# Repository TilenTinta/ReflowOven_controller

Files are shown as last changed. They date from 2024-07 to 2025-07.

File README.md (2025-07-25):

# Reflow Oven Controller

An open-source controller for converting a kitchen toaster oven into a reflow oven.

## Overview

This project consists of a PCB and firmware to convert a classic toaster oven into a temperature-controlled oven for PCB reflow.

### Oven Modes
- **Reflow** - Follows a predefined temperature curve for optimal PCB reflow.
- **Dry** - Maintains a defined temperature for a set duration (useful for drying components, filaments, etc.).

The oven used in this build is a budget-friendly (**40€**) **9L toaster oven** with two quartz heating elements (**BROCK TO9001B**). Despite initial concerns about heating speed, the small chamber allows it to reach the required temperatures quickly. The oven has been additionally insulated for improved performance.

A **solid-state relay (SSR)** is used for controlling the heating elements, and a **12V 5A power supply** powers the entire electronics system.

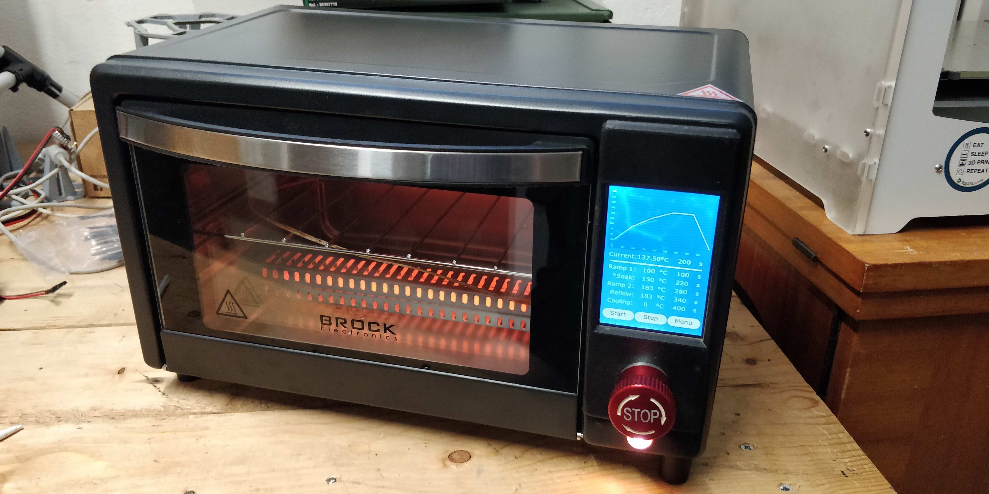
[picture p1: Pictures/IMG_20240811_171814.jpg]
Reflow Oven


---

## PCB

The PCB is a **two-layer board** with components on only one side (**except for the LCD connector, which is on the opposite side**). The board has the **same dimensions and mounting hole positions as the LCD**, allowing them to be stacked using a **3D-printed spacer**.

The LCD used in this build is a **3.5-inch TFT LCD Display Module (320x480) with SPI Interface and Touch Screen (ILI9488 v2).**

### PCB Features
- **Safety switch** for 12V
- **Voltage measurement** (input and buck output)
- **Overtemperature protection** via NTC sensor
- **Input protection** (fuse and reverse polarity protection)
- **Max input voltage: 23V**
- **AUX1 and AUX2** (can handle up to 45V and 500mA, but limited by PCB input voltage)
- **Supports up to two solid-state relays (SSRs)** (PWM amplitude matches input voltage)
- **Supports up to two K-type thermocouples (MAX31855)**
- **Raw USART output & USB output (CH340G)** for monitoring and calibration
- **USB OTG support** (requires core clock adjustment, affecting timer parameters)
- **External 2MB flash (W25Q16JVSNIQ)** for GUI and fonts
- **SWD port** for programming
- **Buzzer**
- **MCU: STM32F411CEU6**

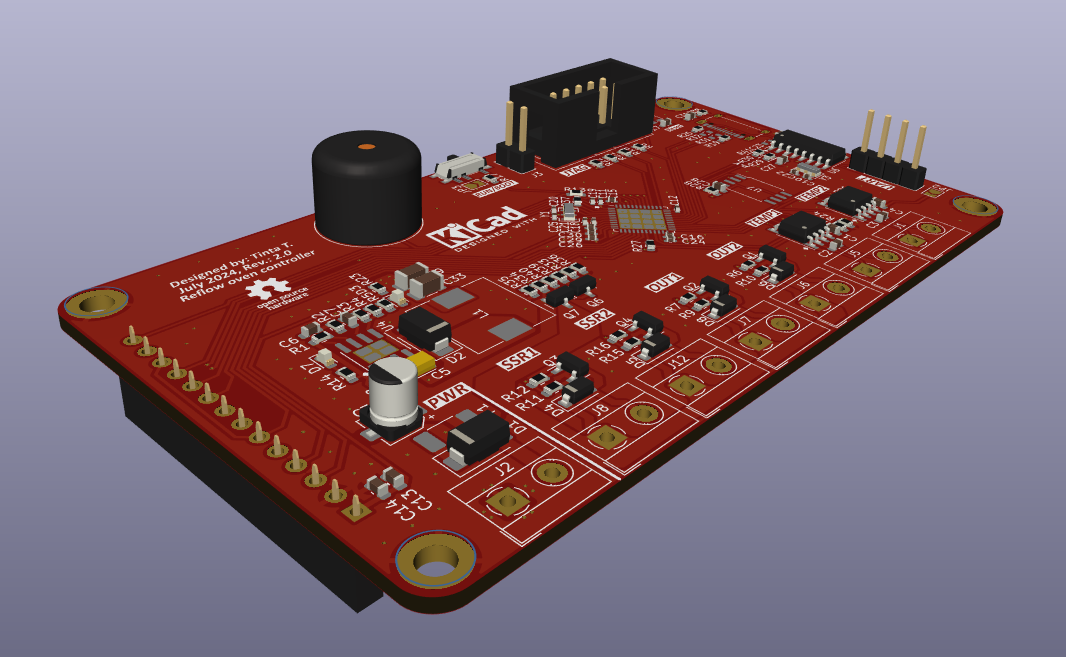
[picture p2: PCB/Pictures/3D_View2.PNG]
PCB 3D View


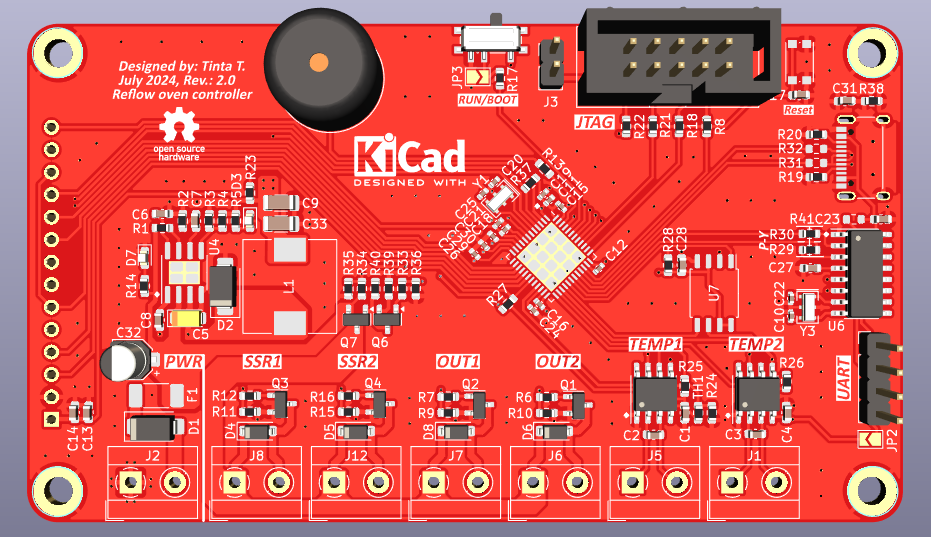
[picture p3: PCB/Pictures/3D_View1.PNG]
PCB 3D View


---

## 3D Models

All parts are printed from **PC plastic** using an **FDM 3D printer**. Alternative plastics can be used, but they must withstand high temperatures. There are two different options for electronics assembly mounting:
- Inside the oven as is in my case. For that you only need to print **Front_frame**

- On the side of the oven. For that you need to print three parts with **external** at the end of model names. Base that screws to the frame has teeth that allows preset angles. For rigit mount use only screw and nut, but you can add a spring under screw head. That will allow setting the angle later.

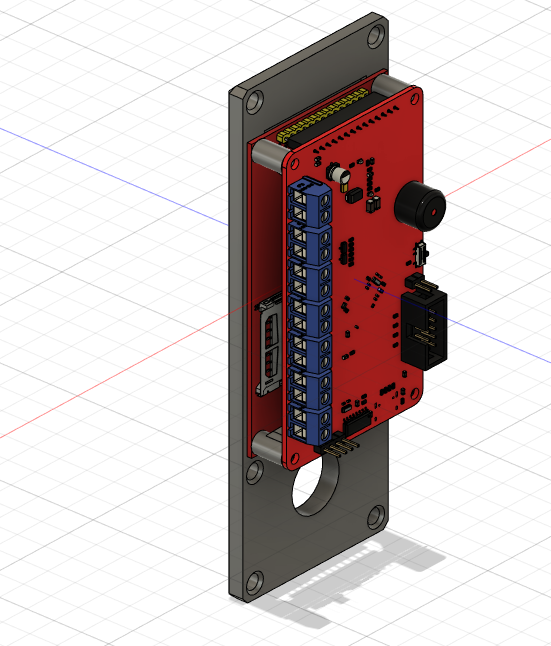
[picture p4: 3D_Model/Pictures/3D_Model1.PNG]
3D Model


---

## External Loader

The **External Loader** is a necessary part of the program. It allows **CubeIDE** to upload data (GUI and fonts) to the external flash chip. If you use a different flash chip, modifications are required to meet the new chip's recommendations. The loader program must be included in the main firmware/IDE.

---

## Firmware

The firmware is not fully compatible with the latest version of the PCB. This update addresses mistakes found in the initial version of the board.

### Missing Features
- **Read input voltage**
- **Read buck voltage**
- **Read NTC sensor**
- **Safety switch** (implemented in code but not tested)

For the GUI, **TouchGFX** with standard elements is used. The only custom file is the **background**.

### External Libraries Used
The libraries for **LCD (with touch)** and **external flash (External Loader)** are not originally written by me but include minor modifications to fit this build. The original work was done by **maudeve-it**:

#### LCD Library:
- [YouTube Video](https://www.youtube.com/watch?v=g1siKaPox88)
- [GitHub Repository](https://github.com/maudeve-it/ILI9XXX-XPT2046-STM32)

#### Flash Library:
- [YouTube Video 1](https://www.youtube.com/watch?v=PO_2ZE1NQF0&list=PL6Fwy7aR3zSlZO3OBppHSzDacE4CGgRqO&index=6)
- [YouTube Video 2](https://www.youtube.com/watch?v=KlG2doCkREM)
- [GitHub Repository](https://github.com/maudeve-it/W25Qxxx_SPI_FLASH_STM32)

---

## License
This project is open-source and available under the **MIT License**.

---

## Contributing
Contributions are welcome! Feel free to submit issues or pull requests to improve the project.

---

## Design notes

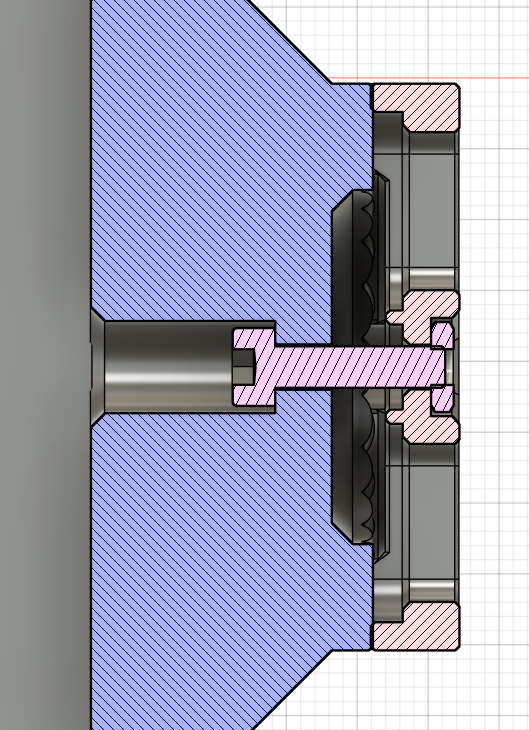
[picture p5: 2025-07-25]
3D_Model/Pictures/External_mount.PNG

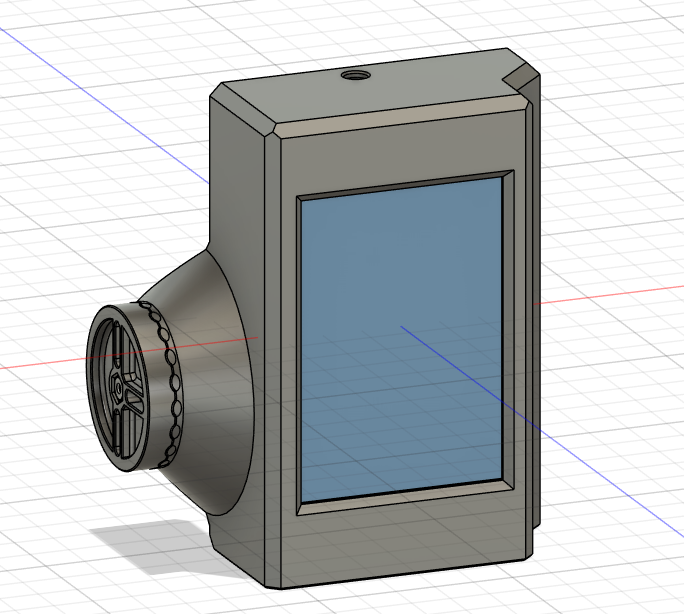
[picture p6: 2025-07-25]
3D_Model/Pictures/External_mount_case.PNG

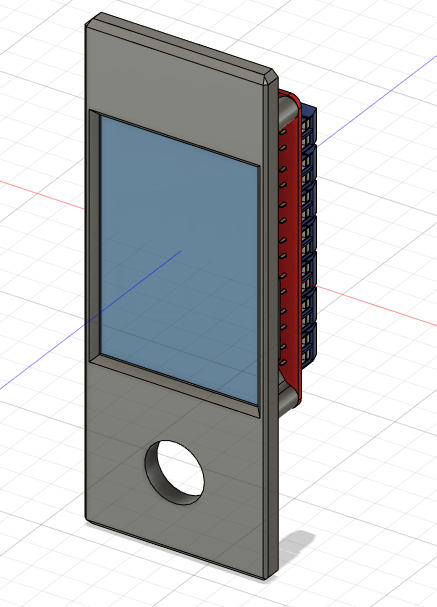
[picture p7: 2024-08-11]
3D_Model/Pictures/3D_Model2.PNG

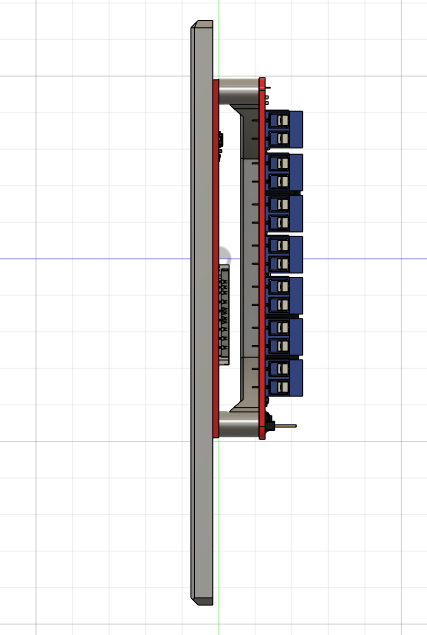
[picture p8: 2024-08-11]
3D_Model/Pictures/3D_Model3.PNG

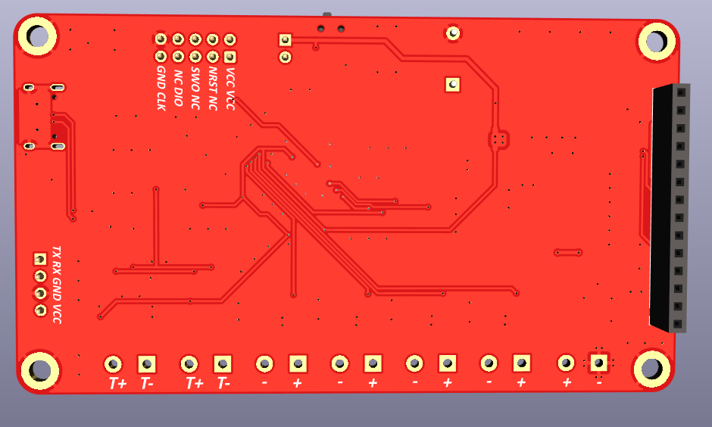
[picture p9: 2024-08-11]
PCB/Pictures/3D_View4.PNG

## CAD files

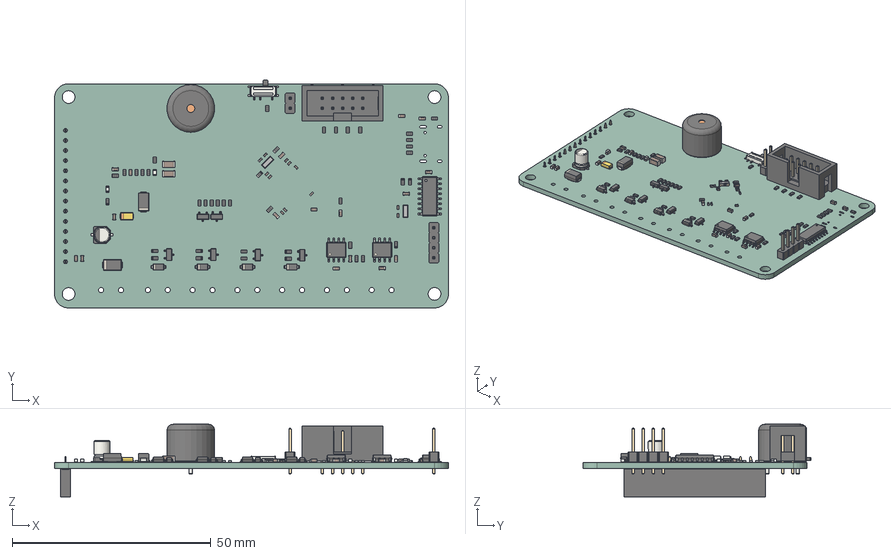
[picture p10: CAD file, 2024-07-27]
3D_Model/PCB.step
99.0 x 57.3 x 18.2 mm
R_0603_1608Metric x 41
Buzzer_12x95RM76
PinHeader_1x04_P254mm_Vertical
C_0402_1005Metric x 12
C_1206_3216Metric x 2
LED_0603_1608Metric x 2
CP_Elec_4x54
muRata_CSTxExxV x 2
SOT_23 x 6
D_SMA x 2
PinHeader_1x02_P254mm_Vertical
C_0603_1608Metric x 17
Fusion_sp
IDC_Header_2x05_P254mm_Vertical
CP_EIA_3216_10_Kemet_I
SOIC_8_39x49mm_P127mm x 2
D_SOD_123 x 4
SOIC_16_39x99mm_P127mm
PinSocket_1x14_P254mm_Vertical
PCB_PCB

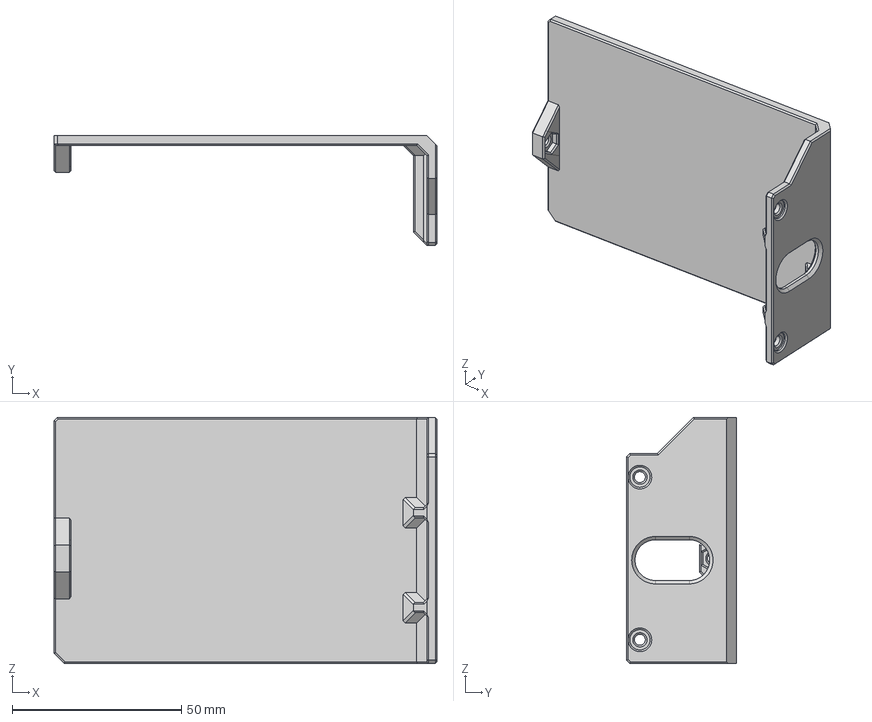
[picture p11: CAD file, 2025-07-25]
3D_Model/STEP/Back_frame_external v19.step
113.0 x 32.5 x 72.6 mm

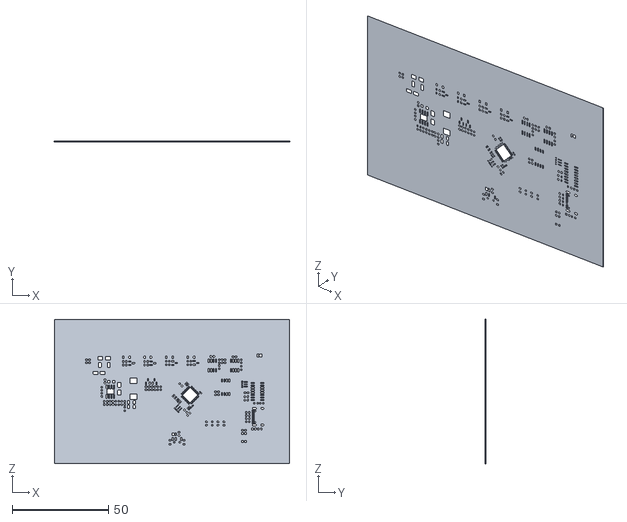
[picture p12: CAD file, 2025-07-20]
PCB/Stencil/Stencil v2.stl
122.1 x 0.15 x 75.0

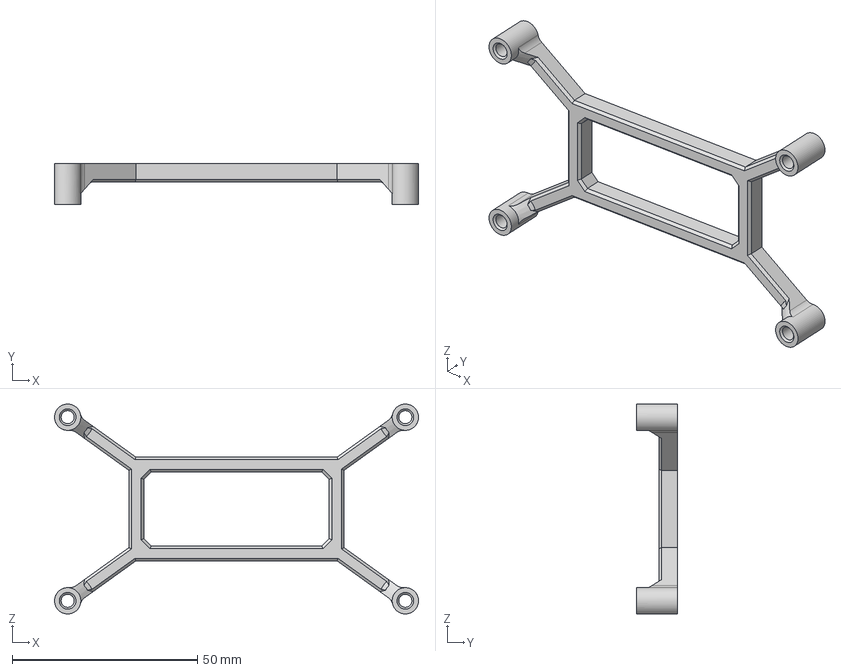
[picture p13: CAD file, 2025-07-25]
3D_Model/STEP/Spacer_PCB-Screen v3.step
98.1 x 11.0 x 56.6 mm

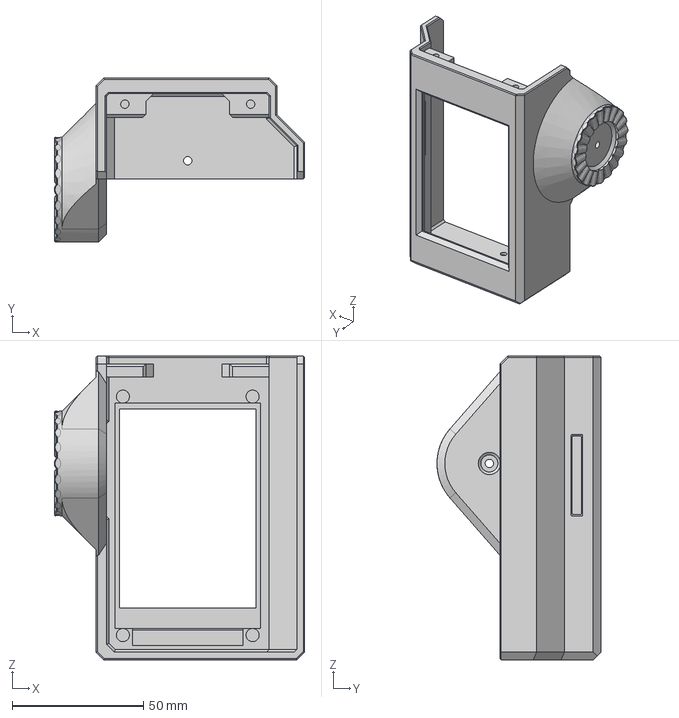
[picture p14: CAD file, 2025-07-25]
3D_Model/STEP/Front_frame_external v40.step
95.5 x 62.6 x 116.0 mm

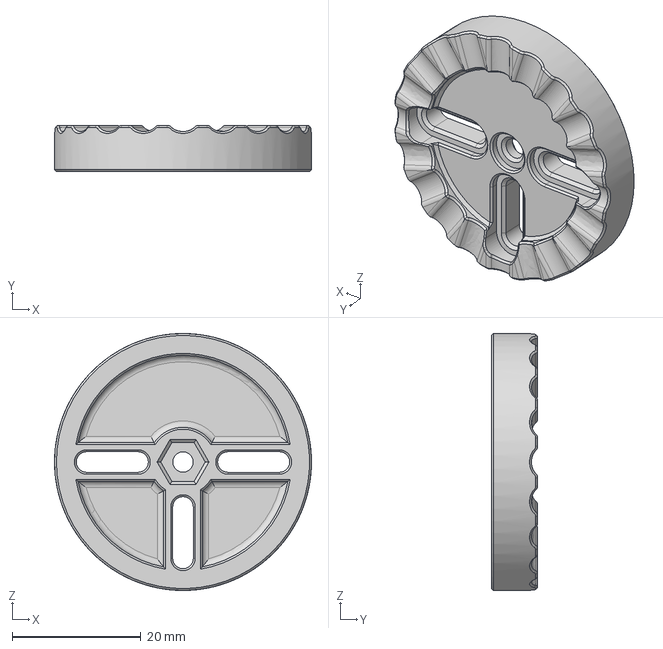
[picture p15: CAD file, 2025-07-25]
3D_Model/STEP/Base_external v7.step
40.0 x 7.20 x 40.0 mm

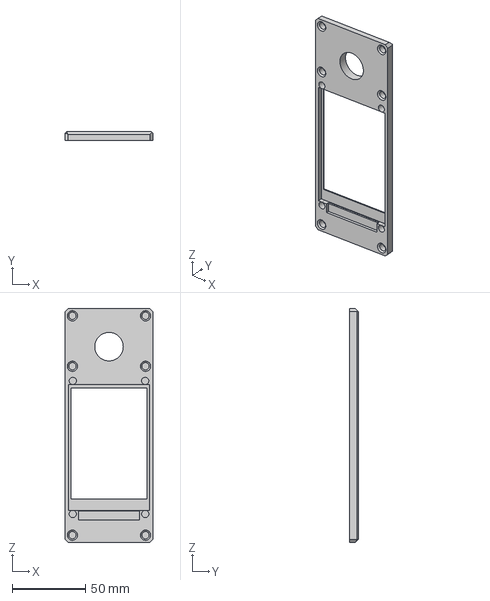
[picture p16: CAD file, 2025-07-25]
3D_Model/STEP/Front_frame v9.step
60.0 x 6.00 x 160.0 mm

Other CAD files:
3D_Model/STL/Back_frame_external v19.stl
3D_Model/STL/Base_external v7.stl
3D_Model/STL/Front_frame v9.stl
3D_Model/STL/Front_frame_external v40.stl
3D_Model/STL/Spacer_PCB-Screen v3.stl
PCB/Stencil/PCB-F_Mask.dxf

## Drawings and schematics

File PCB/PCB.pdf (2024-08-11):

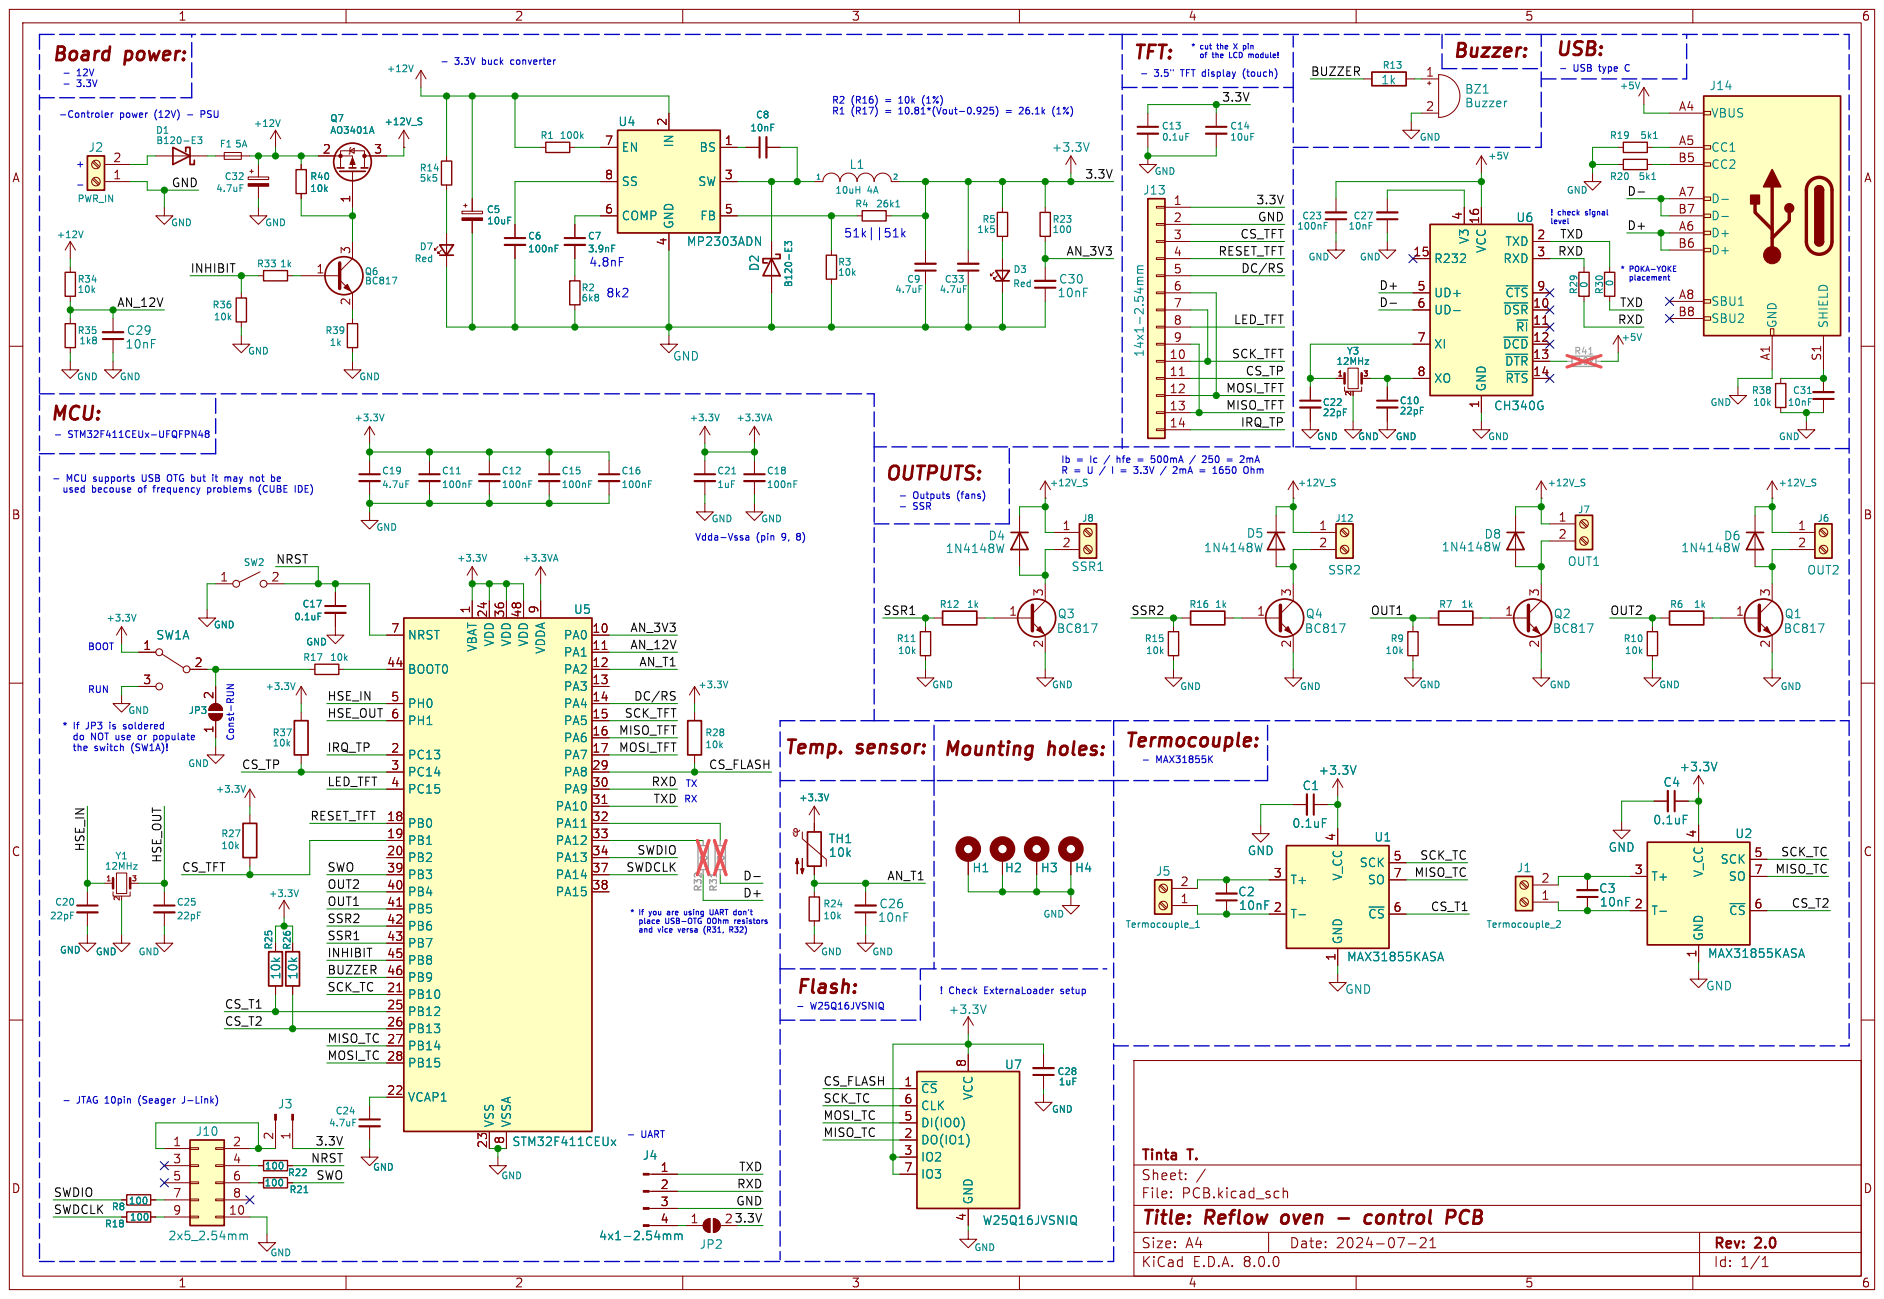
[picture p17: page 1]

4 FB 5 COMP 6 EN 7 SS 8 U4 MP2303ADN

4 FB 5 COMP 6 EN 7 SS 8 D2 B120-E3 C5

1 ~{DSR} 10 ~{RI} 11 ~{DCD} 12 ~{DTR} 13 ~{RTS} 14 R232 15 VCC 16 TXD 2 RXD 3 V3

4 UD+ 5 UD- 6 XI 7 XO 8 ~{CTS}9 U6 CH340G

4 UD+ 5 UD- 6 XI 7 XO 8 ~{CTS}9 C3

Ib = Ic / hfe = 500mA / 250 = 2mA R = U / I = 3.3V / 2mA = 1650 Ohm

- JTAG 10pin (Seager J-Link) Const-RUN

1 PA0 10 PA1 11 PA2 12 PA3 13 PA4 14 PA5 15 PA6 16 PA7 17 PB0 18 PB1 19 PC13 2 PB2 20 PB10 21 VCAP1 22 VSS 23 VDD 24 PB12 25 PB13 26 PB14 27 PB15 28 PA8 29 PC14 3 PA9 30 PA10 31 PA11 32 PA12 33 PA13 34 VDD 36 PA14 37 PA15 38 PB3 39 PC15 4 PB4 40 PB5 41 PB6 42 PB7 43 BOOT0 44 PB8 45 PB9 46 VDD 48 PH0 5 PH1 6 NRST 7 VSSA

4 SCK 5 ~{CS}6 SO 7 U5 STM32F411CEUx VBAT

* If JP3 is soldered
do NOT use or populate

4 SCK 5 ~{CS}6 SO 7 U1 MAX31855KASA GND

* If you are using UART don't place USB-OTG 0Ohm resistors and vice versa (R31, R32)

Id: 1/1 Title: Reflow oven - control PCB

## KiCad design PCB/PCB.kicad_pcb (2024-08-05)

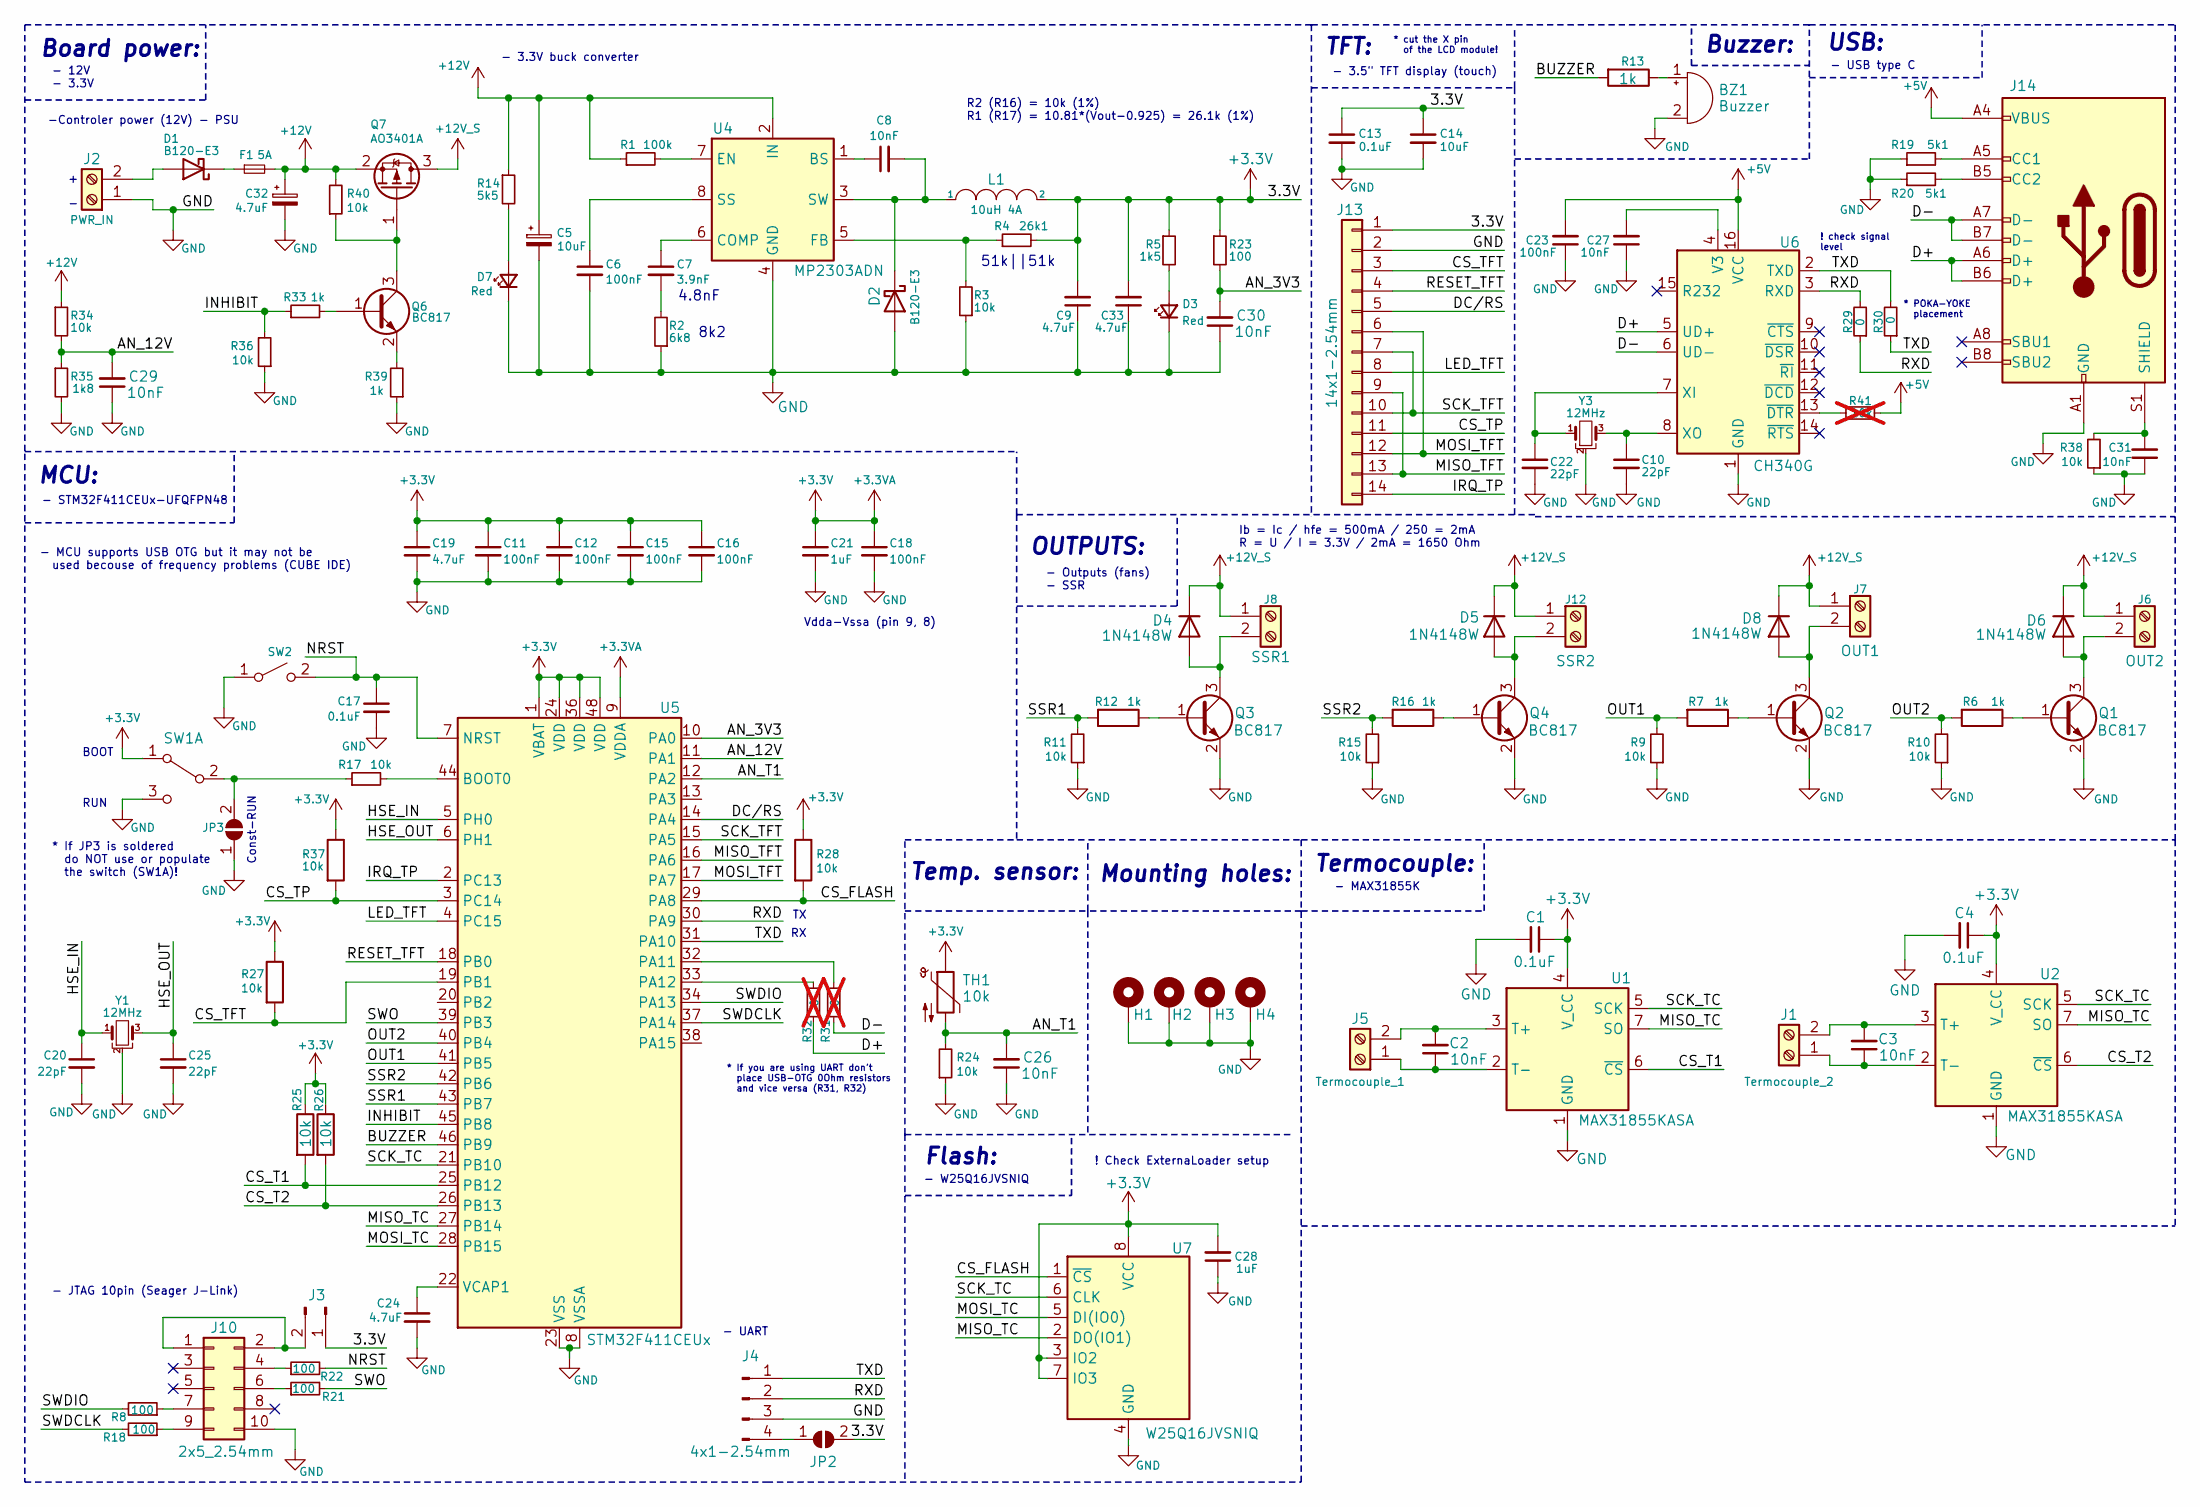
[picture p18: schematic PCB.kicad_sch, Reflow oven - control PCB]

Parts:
BZ1: Buzzer; Buzzer_12x9.5RM7.6
C1, C4, C13, C17: 0.1uF; C_0603_1608Metric
C2, C3, C8, C27, C31: 10nF; C_0603_1608Metric
C5: 10uF; CP_EIA-3216-10_Kemet-I
C6, C23: 100nF; C_0603_1608Metric
C7: 3.9nF; C_0603_1608Metric
C9, C33: 4.7uF; C_1206_3216Metric
C10, C20, C22, C25: 22pF; C_0402_1005Metric
C11, C12, C15, C16, C18: 100nF; C_0402_1005Metric
C14: 10uF; C_0603_1608Metric
C19, C24: 4.7uF; C_0402_1005Metric
C21: 1uF; C_0402_1005Metric
C26, C29, C30: 10nF; C_0402_1005Metric
C28: 1uF; C_0603_1608Metric
C32: 4.7uF; CP_Elec_4x5.4
D1, D2: B120-E3; D_SMA
D3, D7: Red; LED_0603_1608Metric
D4, D5, D6, D8: 1N4148W; D_SOD-123
F1: 5A; Fuse_2010_5025Metric_Pad1.52x2.65mm_HandSolder
H1, H2, H3, H4: MountingHole_Pad; MountingHole_3.2mm_M3_DIN965_Pad
J1: Termocouple_2; TerminalBlock_MetzConnect_Type055_RT01502HDWU_1x02_P5.00mm_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
J2: PWR_IN; TerminalBlock_MetzConnect_Type055_RT01502HDWU_1x02_P5.00mm_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
J3: Conn_01x02_Pin; PinHeader_1x02_P2.54mm_Vertical
J4: 4x1-2.54mm; PinHeader_1x04_P2.54mm_Vertical
J5: Termocouple_1; TerminalBlock_MetzConnect_Type055_RT01502HDWU_1x02_P5.00mm_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
J6: OUT2; TerminalBlock_MetzConnect_Type055_RT01502HDWU_1x02_P5.00mm_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
J7: OUT1; TerminalBlock_MetzConnect_Type055_RT01502HDWU_1x02_P5.00mm_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
J8: SSR1; TerminalBlock_MetzConnect_Type055_RT01502HDWU_1x02_P5.00mm_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
J10: 2x5_2.54mm; IDC-Header_2x05_P2.54mm_Vertical
J12: SSR2; TerminalBlock_MetzConnect_Type055_RT01502HDWU_1x02_P5.00mm_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
J13: 14x1-2.54mm; PinSocket_1x14_P2.54mm_Vertical
J14: USB_C_Receptacle_USB2.0; USB_C_Receptacle_XKB_U262-16XN-4BVC11
JP2, JP3: SolderJumper_2_Open; SolderJumper-2_P1.3mm_Open_TrianglePad1.0x1.5mm
L1: 10uH 4A; L_10.4x10.4_H4.8
Q1, Q2, Q3, Q4, Q6: BC817; SOT-23
Q7: AO3401A; SOT-23
R1: 100k; R_0603_1608Metric
R2: 6k8; R_0603_1608Metric
R3, R9, R10, R11, R15, R17, R24, R25, R26, R27, R28, R34, R36, R37, R38, R40: 10k; R_0603_1608Metric
R4: 26k1; R_0603_1608Metric
R5: 1k5; R_0603_1608Metric
R6, R7, R12, R13, R16, R33, R39: 1k; R_0603_1608Metric
R8, R18, R21, R22, R23: 100; R_0603_1608Metric
R14: 5k5; R_0603_1608Metric
R19, R20: 5k1; R_0603_1608Metric
R29, R30: 0; R_0603_1608Metric
R31, R32: 0; R_0603_1608Metric; not fitted
R35: 1k8; R_0603_1608Metric
R41: 10k; R_0603_1608Metric; not fitted
SW1: SW_DPDT; SW_SPDT_PCM12
SW2: SW_SPST; SW_Push_1P1T_NO_CK_KMR2
TH1: 10k; R_0603_1608Metric
U1, U2: MAX31855KASA; SOIC-8_3.9x4.9mm_P1.27mm
U4: MP2303ADN; SOIC-8-1EP_3.9x4.9mm_P1.27mm_EP2.62x3.51mm
U5: STM32F411CEUx; QFN-48-1EP_7x7mm_P0.5mm_EP5.6x5.6mm
U6: CH340G; SOIC-16_3.9x9.9mm_P1.27mm
U7: W25Q16JVSNIQ; SOIC-8_5.23x5.23mm_P1.27mm
Y1, Y3: 12MHz; Resonator_SMD_Murata_CSTxExxV-3Pin_3.0x1.1mm

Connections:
+3.3V: C1.1, C4.1, C9.2, C11.1, C12.1, C13.1, C14.1, C15.1, C16.1, C18.1, C19.1, C21.1, C28.2, C33.2, J3.1, J13.1, JP2.2 (B), L1.2, R4.2, R5.1, R23.1, R25.1, R26.1, R27.1, R28.1, R37.1, SW1.1 (A), TH1.1, U1.4 (V_CC), U2.4 (V_CC), U5.1 (VBAT), U5.9 (VDDA), U5.24 (VDD), U5.36 (VDD), U5.48 (VDD), U7.3 (IO2), U7.7 (IO3), U7.8 (VCC)
+5V: C23.2, J14.A4 (VBUS), J14.A9 (VBUS), J14.B4 (VBUS), J14.B9 (VBUS), R41.1, U6.16 (VCC)
+12V: C5.1, C32.1, F1.2, Q7.2 (S), R1.1, R14.1, R34.1, R40.2, U4.2 (IN)
+12V_S: D4.1 (K), D5.1 (K), D6.1 (K), D8.1 (K), J6.1, J7.1, J8.1, J12.1, Q7.3 (D)
/AN_3V3: C30.2, R23.2, U5.10 (PA0)
/AN_12V: C29.2, R34.2, R35.1, U5.11 (PA1)
/AN_T1: C26.2, R24.2, TH1.2, U5.12 (PA2)
/BUZZER: R13.2, U5.46 (PB9)
/CS_FLASH: R28.2, U5.29 (PA8), U7.1 (~CS)
/CS_T1: R25.2, U1.6 (~CS), U5.25 (PB12)
/CS_T2: R26.2, U2.6 (~CS), U5.26 (PB13)
/CS_TFT: J13.3, R27.2, U5.19 (PB1)
/CS_TP: J13.11, R37.2, U5.3 (PC14)
/D+: J14.A6 (D+), J14.B6 (D+), R32.1, U6.5 (UD+)
/D-: J14.A7 (D-), J14.B7 (D-), R31.1, U6.6 (UD-)
/DC/RS: J13.5, U5.14 (PA4)
/HSE_IN: C20.1, U5.5 (PH0), Y1.1
/HSE_OUT: C25.1, U5.6 (PH1), Y1.3
/INHIBIT: R33.1, R36.2, U5.45 (PB8)
/IRQ_TP: J13.14, U5.2 (PC13)
/LED_TFT: J13.8, U5.4 (PC15)
/MISO_TC: U1.7 (SO), U2.7 (SO), U5.27 (PB14), U7.2 (DO(IO1))
/MISO_TFT: J13.9, J13.13, U5.16 (PA6)
/MOSI_TC: U5.28 (PB15), U7.5 (DI(IO0))
/MOSI_TFT: J13.6, J13.12, U5.17 (PA7)
/NRST: C17.1, R22.2, SW2.2 (B), U5.7 (NRST)
/OUT1: R7.2, R9.2, U5.41 (PB5)
/OUT2: R6.2, R10.2, U5.40 (PB4)
/RESET_TFT: J13.4, U5.18 (PB0)
/RXD: J4.2, R29.1, R29.2, U5.30 (PA9), U6.3 (RXD)
/SCK_TC: U1.5 (SCK), U2.5 (SCK), U5.21 (PB10), U7.6 (CLK)
/SCK_TFT: J13.7, J13.10, U5.15 (PA5)
/SSR1: R11.2, R12.2, U5.43 (PB7)
/SSR2: R15.2, R16.2, U5.42 (PB6)
/SWDCLK: R18.2, U5.37 (PA14)
/SWDIO: R8.2, U5.34 (PA13)
/SWO: R21.2, U5.39 (PB3)
/TXD: J4.1, R30.1, R30.2, U5.31 (PA10), U6.2 (TXD)
GND: BZ1.2 (+), C1.2, C4.2, C5.2, C6.2, C9.1, C10.2, C11.2, C12.2, C13.2, C14.2, C15.2, C16.2, C17.2, C18.2, C19.2, C20.2, C21.2, C22.2, C23.1, C24.2, C25.2, C26.1, C27.1, C28.1, C29.1, C30.1, C31.1, C32.2, C33.1, D2.2 (A), D3.1 (K), D7.1 (K), H1.1, H2.1, H3.1, H4.1, J2.1, J4.3, J10.10, J13.2, J14.A1 (GND), J14.A12 (GND), J14.B1 (GND), J14.B12 (GND), JP3.1 (A), Q1.2 (E), Q2.2 (E), Q3.2 (E), Q4.2 (E), R2.1, R3.1, R9.1, R10.1, R11.1, R15.1, R19.1, R20.1, R24.1, R35.2, R36.1, R38.1, R39.1, SW1.3 (C), SW2.1 (A), U1.1 (GND), U2.1 (GND), U4.4 (GND), U5.8 (VSSA), U5.23 (VSS), U5.35 (VSS), U5.47 (VSS), U5.49 (VSS), U6.1 (GND), U7.4 (GND), Y1.2, Y3.2
unnamed: BZ1.1 (-), R13.1
unnamed: C7.2, R2.2
unnamed: D1.2 (A), J2.2
unnamed: D1.1 (K), F1.1
unnamed: C8.2, D2.1 (K), L1.1, U4.3 (SW)
unnamed: D3.2 (A), R5.2
unnamed: D4.2 (A), J8.2, Q3.3 (C)
unnamed: D5.2 (A), J12.2, Q4.3 (C)
unnamed: D6.2 (A), J6.2, Q1.3 (C)
unnamed: D7.2 (A), R14.2
unnamed: D8.2 (A), J7.2, Q2.3 (C)
unnamed: C3.1, J1.1, U2.2 (T-)
unnamed: C3.2, J1.2, U2.3 (T+)
unnamed: J4.4, JP2.1 (A)
unnamed: C2.1, J5.1, U1.2 (T-)
unnamed: C2.2, J5.2, U1.3 (T+)
unnamed: J3.2, J10.1, J10.2
unnamed: J10.4, R22.1
unnamed: J10.6, R21.1
unnamed: J10.7, R8.1
unnamed: J10.9, R18.1
unnamed: J14.A5 (CC1), R19.2
unnamed: J14.B5 (CC2), R20.2
unnamed: C31.2, J14.S1 (SHIELD), R38.2
unnamed: JP3.2 (B), R17.1, SW1.2 (B)
unnamed: Q1.1 (B), R6.1
unnamed: Q2.1 (B), R7.1
unnamed: Q3.1 (B), R12.1
unnamed: Q4.1 (B), R16.1
unnamed: Q6.1 (B), R33.2
unnamed: Q6.3 (C), Q7.1 (G), R40.1
unnamed: Q6.2 (E), R39.2
unnamed: C8.1, U4.1 (BS)
unnamed: C7.1, U4.6 (COMP)
unnamed: R1.2, U4.7 (EN)
unnamed: R3.2, R4.1, U4.5 (FB)
unnamed: C6.1, U4.8 (SS)
unnamed: R17.2, U5.44 (BOOT0)
unnamed: R31.2, U5.32 (PA11)
unnamed: R32.2, U5.33 (PA12)
unnamed: C24.1, U5.22 (VCAP1)
unnamed: C27.2, U6.4 (V3)
unnamed: C22.1, U6.7 (XI), Y3.1
unnamed: C10.1, U6.8 (XO), Y3.3
unnamed: R41.2, U6.13 (~DTR)

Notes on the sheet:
Ib = Ic / hfe = 500mA / 250 = 2mA R = U / I = 3.3V / 2mA = 1650 Ohm
R2 (R16) = 10k (1%) R1 (R17) = 10.81*(Vout-0.925) = 26.1k (1%)
8k2
BOOT
Temp. sensor:
* POKA-YOKE placement
! check signal level
MCU:
Vdda-Vssa (pin 9, 8)
Buzzer:
* cut the X pin of the LCD module!
* If JP3 is soldered do NOT use or populate the switch (SW1A)!
4.8nF
- MAX31855K
Termocouple:
- UART
OUTPUTS:
Board power:
- JTAG 10pin (Seager J-Link)
- MCU supports USB OTG but it may not be used becouse of frequency problems (CUBE IDE)
TFT:
- Outputs (fans) - SSR
! Check ExternaLoader setup
- 12V - 3.3V
- 3.3V buck converter
- 3.5" TFT display (touch)
USB:
Mounting holes:
- USB type C
Flash:
-Controler power (12V) - PSU
Const-RUN
51k||51k
* If you are using UART don't place USB-OTG 0Ohm resistors and vice versa (R31, R32)
- W25Q16JVSNIQ
RUN
- STM32F411CEUx-UFQFPN48

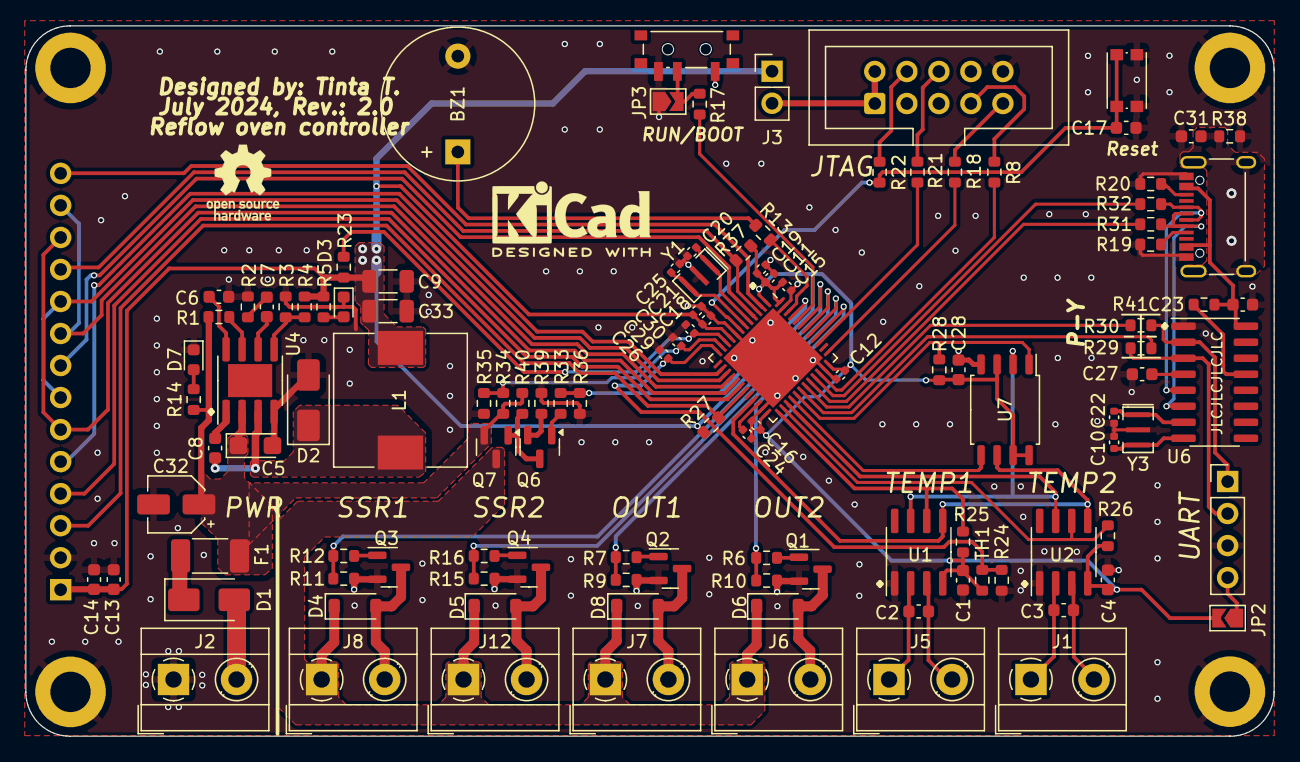
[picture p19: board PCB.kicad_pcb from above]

Board: 2 copper layers, 99.0 x 56.3 mm, 120 parts (1 on the bottom side), 84 nets.

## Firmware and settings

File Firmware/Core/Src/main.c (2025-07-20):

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
/* Includes ------------------------------------------------------------------*/
#include "main.h"
#include "app_touchgfx.h"

CRC_HandleTypeDef hcrc;

SPI_HandleTypeDef hspi1;
SPI_HandleTypeDef hspi2;
DMA_HandleTypeDef hdma_spi1_tx;

TIM_HandleTypeDef htim2;
TIM_HandleTypeDef htim3;
TIM_HandleTypeDef htim4;

UART_HandleTypeDef huart1;

void SystemClock_Config(void);
static void MX_GPIO_Init(void);
static void MX_DMA_Init(void);
static void MX_USART1_UART_Init(void);
static void MX_SPI1_Init(void);
static void MX_CRC_Init(void);
static void MX_SPI2_Init(void);
static void MX_TIM3_Init(void);
static void MX_TIM2_Init(void);
static void MX_TIM4_Init(void);
/* USER CODE BEGIN PFP */
// Define structs
Thermocouple thermocouple1;
Thermocouple thermocouple2;

/* USER CODE END PFP */

/* USER CODE BEGIN 0 */

// Default values for oven preset
OvenParameters ovenParameters = {

		// device operating variables
		.initEnd = 0,
		.deviceState = 0,
		.pageChageNo = 0,
		.reflowSetupStep = 0,
		.pidSetupStep = 0,
		.tempNTC = 0.0f,
		.tempThermo = 0.0f,
		.PID_trig = 0,
		.saveFlash = 0,
		.reflowStage = 0,
		.tempSPDelta = 0,
		.setpointCal = 1,
		.totalReflowTime = 0,
		.endTimeStage = 1,
		.tempThermoAvg = 0,
		.addPoint = 0,
		.profileNoEdit = 0,

		// retentive variables
		.Kp = 10.0f,	// 3.96
		.Ki = 0.1f,		// 0.078
		.Kd = 4.5f,		// 49.5
		.profileNoSelected = 2,
		.lastUsedMode = 0,

		.dualProbes = 0,
		.dualSSRs = 0,
		.units = 0,
		.AUX1 = 0,
		.AUX2 = 0,
		.firstBoot = 0,

		// device runing variables
		.startStop = 0,
		.actionTick = 0,
		.cntTimerTick = 0,
		.cntSecond = 0,
		.cntMinute = 0,
		.cntHour = 0
};

// Default values for profiles
ReflowProfiles reflowProfiles = {
		.profile1Temp = {150, 160, 210, 210, 20},
		.profile1Time = {120, 140, 390, 400, 450},

		.profile2Temp = {100, 150, 183, 183, 20},
		.profile2Time = {100, 220, 280, 340, 400},

		.profile3Temp = {100, 150, 183, 183, 20},
		.profile3Time = {100, 220, 280, 340, 400},

		.profile4Temp = {100, 150, 183, 183, 20},
		.profile4Time = {100, 220, 280, 340, 400},

		.profile5Temp = {100, 150, 183, 183, 20},
		.profile5Time = {100, 220, 280, 340, 400}
};

// Default values for drying
DryPreset dryPreset = {
		.dryTemp = 100,
		.dryTime = 60
};

// Default values for error codes
OvenErrorCodes ovenErrorCodes = {
		.ADC12V = 0,
		.ADC3V3 = 0,
		.NTCErr = 0,
		.thermoCouple1Err = 0,
		.thermoCouple2Err = 0
};


// variables init
float AN_V_12V = 0;				// Measured 12V voltage
float AN_V_3V3 = 0;				// Measured 3.3V voltage
uint8_t INHIBIT = 0;			// enable 12V bus

uint8_t saveToFlash = 0;		// protect writing to flash every time (connected with KEEP_FLASH_DATA)
float tempAVG1[5] = {};			// values of temp from thermocouple 1 in one second to calculate average value
float tempAVG2[5] = {};			// values of temp from thermocouple 2 in one second to calculate average value
uint8_t cntTempArray = 0;		// counter for temperature array
uint8_t endOfCycle = 0;			// flag to indicate the end of drying or reflow
float startingTemp = 0; 		// used to set setpoints
uint16_t endTemp = 0;			// temperature expected at the end of each step
uint8_t thermalRnwyCnt = 0;		// counter for thermal runaway time - one tick is one second
uint16_t rnwyTempOld = 0;		// previous temp value for detecting thermal runaways

/* USER CODE END 0 */

/**
  * @brief  The application entry point.
  * @retval int
  */
int main(void)
{

  /* USER CODE BEGIN 1 */

	// TODO: Celsius -> Fahrenheit

	// PID parameters
	PID pid;
	PIDInit(&pid);

  /* USER CODE END 1 */

  /* MCU Configuration--------------------------------------------------------*/

  /* Reset of all peripherals, Initializes the Flash interface and the Systick. */
  HAL_Init();

  /* Configure the system clock */
  SystemClock_Config();

  /* Initialize all configured peripherals */
  MX_GPIO_Init();
  MX_DMA_Init();
  MX_USART1_UART_Init();
  MX_SPI1_Init();
  MX_CRC_Init();
  MX_SPI2_Init();
  MX_TIM3_Init();
  MX_TIM2_Init();
  MX_TIM4_Init();
  MX_TouchGFX_Init();
  /* USER CODE BEGIN 2 */

  // Set default state of CS and other pins
  HAL_GPIO_WritePin(TOUCH_CS_GPIO_Port, TOUCH_CS_Pin, GPIO_PIN_SET);
  HAL_GPIO_WritePin(DISPL_CS_GPIO_Port, DISPL_CS_Pin, GPIO_PIN_SET);
  HAL_GPIO_WritePin(FLASH_CS_GPIO_Port, FLASH_CS_Pin, GPIO_PIN_SET);
  HAL_GPIO_WritePin(TERMO1_CS_GPIO_Port, TERMO1_CS_Pin, GPIO_PIN_SET);
  HAL_GPIO_WritePin(TERMO2_CS_GPIO_Port, TERMO2_CS_Pin, GPIO_PIN_SET);
  HAL_GPIO_WritePin(AUX_OUT1_GPIO_Port, AUX_OUT1_Pin, GPIO_PIN_RESET);
  HAL_GPIO_WritePin(AUX_OUT2_GPIO_Port, AUX_OUT2_Pin, GPIO_PIN_RESET);
  HAL_GPIO_WritePin(DISPL_LED_GPIO_Port, DISPL_LED_Pin, GPIO_PIN_SET);

  Displ_Init(Displ_Orientat_90);			// initialize display controller - set orientation parameter as per TouchGFX setup
  Displ_BackLight('I');  					// initialize backlight
  touchgfxSignalVSync();
  HAL_TIM_Base_Start_IT(&TGFX_T);			// start TouchGFX tick timer

  /* USER CODE END 2 */

  /* Infinite loop */
  /* USER CODE BEGIN WHILE */


  while (1)
  {

	  if (Touch_GotATouch(0))
		  touchgfxSignalVSync();
    /* USER CODE END WHILE */

  MX_TouchGFX_Process();
    /* USER CODE BEGIN 3 */

	  // Timer interrupt trigger (5Hz)
	  if (ovenParameters.actionTick == 1)
	  {
		  // To start timer the device must be in run mode (startStop = 1)
		  if (ovenParameters.startStop == 1)
		  {
			  // Ticks to seconds
			  // that part of code is implemented in interrupt routine becouse of precision

			  // Seconds to minutes
			  if (ovenParameters.cntSecond >= secInMin)
			  {
				  ovenParameters.cntSecond = 0;
				  ovenParameters.cntMinute ++;


				// THERMAL RUNAWAY LOGIC //
				/* if the device has enabled one or both SSRs and
				 * the temperature doesn't reach setted delta temerature
				 * the error is triggered
				*/
				#ifdef THERMAL_RUNAWAY_EN
				  rnwyTempOld = ovenParameters.tempThermoAvg;

				  if (ovenParameters.dualSSRs == 0)				 // The value can be adjusted
				  {
					  if (TIM4->CCR2 > 5000)
					  {
						  thermalRnwyCnt = ((rnwyTempOld - ovenParameters.tempThermoAvg) < RUNAWAY_TEMP) ? (thermalRnwyCnt + 1) : 0;
					  }
				  }
				  else
				  {
					  if (TIM4->CCR2 > 5000 || TIM4->CCR1 > 5000) // The value can be adjusted
					  {
						  thermalRnwyCnt = ((rnwyTempOld - ovenParameters.tempThermoAvg) < RUNAWAY_TEMP) ? (thermalRnwyCnt + 1) : 0;
					  }
				  }

				  // trigger the thermal runaway error
				  if (thermalRnwyCnt >= RUNAWAY_TIME)
				  {
					  ovenErrorCodes.thermalRunaway ++;
					  ovenParameters.deviceState = STATE_ERROR;
				  }

				  rnwyTempOld = ovenParameters.tempThermoAvg;	 // save current temp as old temp
				#endif
			  }

			  // Minutes to hours
			  if (ovenParameters.cntMinute >= minInH)
			  {
				  ovenParameters.cntMinute = 0;
				  ovenParameters.cntHour ++;
			  }

			  if (ovenParameters.deviceState == STATE_DRY)
			  {
				  uint32_t timeDryEst = dryPreset.dryTime - (ovenParameters.cntHour * 60 + ovenParameters.cntMinute);
				  if (timeDryEst == 0 && ovenParameters.startStop == 1 && (ovenParameters.cntHour != 0 || ovenParameters.cntMinute != 0)) endOfCycle = 1;
			  }
			  else if (ovenParameters.deviceState == STATE_REFLOW)
			  {
				  uint32_t timeReflowEst = ovenParameters.totalReflowTime - (ovenParameters.cntMinute * 60 + ovenParameters.cntSecond);
				  if (timeReflowEst == 0 && ovenParameters.startStop == 1 && ovenParameters.totalReflowTime != 0) endOfCycle = 1;
			  }

		  }
		  else
		  {
			  ovenParameters.cntHour = 0;
			  ovenParameters.cntMinute = 0;
			  ovenParameters.cntSecond = 0;
			  TIM4->CCR2 = 0;
			  TIM4->CCR1 = 0;
		  }

		  // Calculate average temperatures used for regulation
		  if (cntTempArray >= tickInSec)
		  {
			  pid.tempAVGThermo1 = 0;
			  pid.tempAVGThermo2 = 0;

			  if (ovenParameters.dualProbes == 0)
			  {
				  for (uint8_t i = 0; i < tickInSec; i++)
				  {
					  pid.tempAVGThermo1 += tempAVG1[i];
				  }

				  pid.tempAVGThermo1 = pid.tempAVGThermo1 / tickInSec;
				  ovenParameters.tempThermoAvg = pid.tempAVGThermo1;

				  // Over temperature protection
				  if (ovenParameters.tempThermoAvg >= OVERTEMP_ERR)
				  {
					  ovenErrorCodes.overTemp ++;
					  ovenParameters.startStop = 0;
					  ovenParameters.deviceState = STATE_ERROR;
				  }
			  }

			  if (ovenParameters.dualProbes == 1)
			  {
				  for (uint8_t i = 0; i < tickInSec; i++)
				  {
					  pid.tempAVGThermo1 += tempAVG1[i];
					  pid.tempAVGThermo2 += tempAVG2[i];
				  }

				  pid.tempAVGThermo1 = pid.tempAVGThermo1 / tickInSec;
				  pid.tempAVGThermo2 = pid.tempAVGThermo2 / tickInSec;

				  ovenParameters.tempThermoAvg = (pid.tempAVGThermo1 + pid.tempAVGThermo2) / 2;

				  // Over temperature protection
				  if (ovenParameters.tempThermoAvg >= OVERTEMP_ERR)
				  {
					  ovenErrorCodes.overTemp ++;
					  ovenParameters.startStop = 0;
					  ovenParameters.deviceState = STATE_ERROR;
				  }
			  }

			  // Clear array
			  for (uint8_t i = 0; i < tickInSec; i++)
			  {
				  tempAVG1[i] = 0;
				  tempAVG2[i] = 0;
			  }

			  cntTempArray = 0;
		  }


		  // Read thermocouple 1
		  if (ovenParameters.dualProbes == 0)
		  {
			  ReadThermocoupleTemp(&thermocouple1, &hspi2, TERMO1_CS_GPIO_Port, TERMO1_CS_Pin);
			  if (thermocouple1.cntFault == 5)
			  {
				  ovenParameters.deviceState = STATE_ERROR;
				  ovenErrorCodes.thermoCouple1Err = 1;
			  }

			  tempAVG1[cntTempArray] = thermocouple1.temperature_C;

			  ovenParameters.tempThermo = thermocouple1.temperature_C; // get temp to show on screen
		  }

		  // Read thermocouple 1 and thermocouple 2
		  if (ovenParameters.dualProbes == 1)
		  {
			  ReadThermocoupleTemp(&thermocouple1, &hspi2, TERMO1_CS_GPIO_Port, TERMO1_CS_Pin);
			  if (thermocouple1.cntFault == 5)
			  {
				  ovenParameters.deviceState = STATE_ERROR;
				  ovenErrorCodes.thermoCouple1Err = 1;
			  }

			  tempAVG1[cntTempArray] = thermocouple1.temperature_C;

			  ReadThermocoupleTemp(&thermocouple2, &hspi2, TERMO2_CS_GPIO_Port, TERMO2_CS_Pin);
			  if (thermocouple2.cntFault == 5)
			  {
				  ovenParameters.deviceState = STATE_ERROR;
				  ovenErrorCodes.thermoCouple2Err = 1;
			  }

			  tempAVG2[cntTempArray] = thermocouple2.temperature_C;

			  ovenParameters.tempThermo = thermocouple1.temperature_C;
			  ovenParameters.tempThermo += thermocouple2.temperature_C;
			  ovenParameters.tempThermo = ovenParameters.tempThermo / 2; // get average temp from both probes to show on screen
		  }

		  cntTempArray ++;

		  // Print data on serial port
			#ifdef UART_EN
			  // Print data
			  char message[50] = {'\0'};
			  sprintf((char *)message, "Probe1 = %.2f\r\n", ovenParameters.tempThermo); // added tick in settings to allow float serial data
			  HAL_UART_Transmit(&huart1, (uint8_t*)message, strlen((char*)message), 100);
			#endif

		  // RESET TICK TIMER - timer callback declared in z_displ_ILI9XXX.h file
		  ovenParameters.actionTick = 0;

	  }


	  // Save variables to flash
	  if (ovenParameters.saveFlash == 1)
	  {
		  WriteVarToFlash();
	  }


	  ///////////// STATE MACHINE /////////////
	  switch(ovenParameters.deviceState)
	  {
	  case STATE_INIT:
		  //////////////////////////////////////////////////////////////////////////////////////////////////////

		  uint8_t err = 0; // error
		  uint8_t erase = 0;

		  // FLASH
		  if (!Flash_Init())
		  {
			while(1){}
		  }

		  // Detect if these is the first boot after firmware uploading (var .firstBoot is from flash)
		#ifndef KEEP_FLASH_DATA
		  erase = 1;
		#endif

		  // Read all variables that are saved in flash
		  ReadVarFromFlash(erase);

		  if (ovenParameters.firstBoot == 1)
		  {
			#ifdef DUAL_PROBE
		  	  ovenParameters.dualProbes = 1;
			#endif

			#ifdef DUAL_SSR
		  	  ovenParameters.dualSSRs = 1;
			#endif

			#ifdef AUX1_EN
		  	  ovenParameters.AUX1 = 1;
			#endif

			#ifdef AUX2_EN
		  	  ovenParameters.AUX2 = 1;
			#endif

		  	  // Detect first boot and save the default variables
		  	  ovenParameters.firstBoot = 0;
		  	  WriteVarToFlash();
		  }

		  HAL_Delay(1000); // wait 1 second for all devices to power on

		  // Set variables to starting values
		  ovenParameters.profileNoEdit = ovenParameters.profileNoSelected;


		  // TODO:
		  // ... read
		  AN_V_12V = 12;  // DELETE
		  AN_V_3V3 = 3.3; // DELETE
		  // Check input voltage //
		  if (AN_V_12V < MIN_IN_VOLTAGE)
		  {
			  err++;
			  ovenErrorCodes.ADC12V = 1;
		  }

		  // Check buck output voltage //
		  if (AN_V_3V3 < MIN_BUCK_VOLTAGE)
		  {
			  err++;
			  ovenErrorCodes.ADC3V3 = 1;
		  }


		  // Check thermocouples //
		  // Probe 1
		  if (ovenParameters.dualProbes == 0)
		  {
			  CheckThermocouple(&thermocouple1, &hspi2, TERMO1_CS_GPIO_Port, TERMO1_CS_Pin);
			  if (thermocouple1.fault == 1)
			  {
				  ovenErrorCodes.thermoCouple1Err = 1;
				  err++;
			  }
		  }

		  // Probe 2
		  if (ovenParameters.dualProbes == 1)
		  {
			  CheckThermocouple(&thermocouple1, &hspi2, TERMO1_CS_GPIO_Port, TERMO1_CS_Pin);
			  if (thermocouple1.fault == 1)
			  {
				  ovenErrorCodes.thermoCouple1Err = 1;
				  err++;
			  }

			  CheckThermocouple(&thermocouple2, &hspi2, TERMO2_CS_GPIO_Port, TERMO2_CS_Pin);
			  if (thermocouple2.fault == 1)
			  {
				  ovenErrorCodes.thermoCouple2Err = 1;
				  err++;
			  }
		  }


		  // NTC temperature //
		  // ... read
		  ovenParameters.tempNTC = 30; // DELETE

		  if (ovenParameters.tempNTC > NTC_MAX_TEMP)
		  {
			  err++;
			  ovenErrorCodes.NTCErr = 1;
		  }


		  // Check error counter //
		  if (err > 0)
		  {
			  ovenParameters.deviceState = STATE_ERROR; // Send device to error state
			 HAL_Delay(2000);

			 ovenParameters.initEnd = 1;
			 // change screen
			 ovenParameters.pageChageNo = 3; 			// Error
		  }
		  else
		  {
			  HAL_GPIO_WritePin(INHIBIT_GPIO_Port, INHIBIT_Pin, GPIO_PIN_SET); // Enable inhibit
			  ovenParameters.initEnd = 1;
			  rnwyTempOld = ovenParameters.tempThermo; 		// set start/default temp value

			#ifndef PID_CAL
				  HAL_TIM_PWM_Start(&htim4, TIM_CHANNEL_2); // enable output for SSR1
				  TIM4->CCR2 = 0;

				  HAL_TIM_PWM_Start(&htim4, TIM_CHANNEL_1); // enable output for SSR2
				  TIM4->CCR1 = 0;
			#endif

			  // continue in reflow mode
			  if (ovenParameters.lastUsedMode == 0)
			  {
				  HAL_Delay(2000);
				  // change screen
				  ovenParameters.deviceState = STATE_REFLOW;
				  ovenParameters.pageChageNo = 1; 			// Reflow
			  }

			  // continue in drying mode
			  if (ovenParameters.lastUsedMode == 1)
			  {
				  HAL_Delay(2000);
				  // change screen
				  ovenParameters.deviceState = STATE_DRY;
				  ovenParameters.pageChageNo = 2; 			// Dry
			  }
		  }

		  break;

	  case STATE_ERROR:
		  //////////////////////////////////////////////////////////////////////////////////////////////////////
		  // DO NOTHING, INVESTIGATE THE PROBLEM
		  break;

	  case STATE_REFLOW:
		  //////////////////////////////////////////////////////////////////////////////////////////////////////

		  // End of reflow profile
		  if (endOfCycle == 1)
		  {
			  ovenParameters.startStop = 0; // end of reflow
			  TIM4->CCR2 = 0;
			  endOfCycle = 0;
			  ovenParameters.reflowStage = 0;
			  ovenParameters.setpointCal = 1;
			  HAL_GPIO_WritePin(BUZZER_GPIO_Port, BUZZER_Pin, GPIO_PIN_SET);
			  HAL_Delay(50);
			  HAL_GPIO_WritePin(BUZZER_GPIO_Port, BUZZER_Pin, GPIO_PIN_RESET);
		  }

		  // Get current time of reflow in seconds
		  uint16_t timeSeconds = ovenParameters.cntMinute * 60 + ovenParameters.cntSecond;

		  // Calculate delta to use as setpoint, trigered every stage change (5 times)
		  if (ovenParameters.setpointCal == 0)
		  {
			  uint16_t startTime = 0;
			  uint16_t reflowTimeDelta = 0;
			  uint16_t startTemp = round(ovenParameters.tempThermo); // can be used even these value
			  uint16_t endTime = 0;
			  int16_t tempdelta = 0;
			  ovenParameters.tempSPDelta = 0;

			  // set end time of current stage
			  switch(ovenParameters.profileNoSelected)
			  {
				  case 1:
					  // Get entire time of profile
					  ovenParameters.totalReflowTime = reflowProfiles.profile1Time[4];

					  // get time delta between two stages
					  if (ovenParameters.reflowStage != 0) startTime = reflowProfiles.profile1Time[ovenParameters.reflowStage - 1];
					  endTime = reflowProfiles.profile1Time[ovenParameters.reflowStage];
					  ovenParameters.endTimeStage = endTime;
					  reflowTimeDelta = endTime - startTime;

					  // get temp delta to set setpoint
					  if (ovenParameters.reflowStage != 0) startTemp = reflowProfiles.profile1Temp[ovenParameters.reflowStage - 1];
					  tempdelta = reflowProfiles.profile1Temp[ovenParameters.reflowStage] - startTemp;
					  ovenParameters.tempSPDelta = tempdelta / (float)reflowTimeDelta;

					  // get stage end temp
					  endTemp = reflowProfiles.profile1Temp[ovenParameters.reflowStage];

					  // set starting temp
					  startingTemp = round(ovenParameters.tempThermo);

					  break;

				  case 2:
					  // Get entire time of profile
					  ovenParameters.totalReflowTime = reflowProfiles.profile2Time[4];

					  // get time delta between two stages
					  if (ovenParameters.reflowStage != 0) startTime = reflowProfiles.profile2Time[ovenParameters.reflowStage - 1];
					  endTime = reflowProfiles.profile2Time[ovenParameters.reflowStage];
					  ovenParameters.endTimeStage = endTime;
					  reflowTimeDelta = endTime - startTime;

					  // get temp delta to set setpoint
					  if (ovenParameters.reflowStage != 0) startTemp = reflowProfiles.profile2Temp[ovenParameters.reflowStage - 1];
					  tempdelta = reflowProfiles.profile2Temp[ovenParameters.reflowStage] - startTemp;
					  ovenParameters.tempSPDelta = (tempdelta / (float)reflowTimeDelta);

					  // get stage end temp
					  endTemp = reflowProfiles.profile2Temp[ovenParameters.reflowStage];

					  // set starting temp
					  startingTemp = round(ovenParameters.tempThermo);

					  break;

				  case 3:
					  // Get entire time of profile
					  ovenParameters.totalReflowTime = reflowProfiles.profile3Time[4];

					  // get time delta between two stages
					  if (ovenParameters.reflowStage != 0) startTime = reflowProfiles.profile3Time[ovenParameters.reflowStage - 1];
					  endTime = reflowProfiles.profile3Time[ovenParameters.reflowStage];
					  ovenParameters.endTimeStage = endTime;
					  reflowTimeDelta = endTime - startTime;

					  // get temp delta to set setpoint
					  if (ovenParameters.reflowStage != 0) startTemp = reflowProfiles.profile3Temp[ovenParameters.reflowStage - 1];
					  tempdelta = reflowProfiles.profile3Temp[ovenParameters.reflowStage] - startTemp;
					  ovenParameters.tempSPDelta = (tempdelta / (float)reflowTimeDelta);

					  // get stage end temp
					  endTemp = reflowProfiles.profile3Temp[ovenParameters.reflowStage];

					  // set starting temp
					  startingTemp = round(ovenParameters.tempThermo);

					  break;

				  case 4:
					  // Get entire time of profile
					  ovenParameters.totalReflowTime = reflowProfiles.profile4Time[4];

					  // get time delta between two stages
					  if (ovenParameters.reflowStage != 0) startTime = reflowProfiles.profile4Time[ovenParameters.reflowStage - 1];
					  endTime = reflowProfiles.profile4Time[ovenParameters.reflowStage];
					  ovenParameters.endTimeStage = endTime;
					  reflowTimeDelta = endTime - startTime;

					  // get temp delta to set setpoint
					  if (ovenParameters.reflowStage != 0) startTemp = reflowProfiles.profile4Temp[ovenParameters.reflowStage - 1];
					  tempdelta = reflowProfiles.profile4Temp[ovenParameters.reflowStage] - startTemp;
					  ovenParameters.tempSPDelta = (tempdelta / (float)reflowTimeDelta);

					  // get stage end temp
					  endTemp = reflowProfiles.profile4Temp[ovenParameters.reflowStage];

					  // set starting temp
					  startingTemp = round(ovenParameters.tempThermo);

					  break;

				  case 5:
					  // Get entire time of profile
					  ovenParameters.totalReflowTime = reflowProfiles.profile5Time[4];

					  // get time delta between two stages
					  if (ovenParameters.reflowStage != 0) startTime = reflowProfiles.profile5Time[ovenParameters.reflowStage - 1];
					  endTime = reflowProfiles.profile5Time[ovenParameters.reflowStage];
					  ovenParameters.endTimeStage = endTime;
					  reflowTimeDelta = endTime - startTime;

					  // get temp delta to set setpoint
					  if (ovenParameters.reflowStage != 0) startTemp = reflowProfiles.profile5Temp[ovenParameters.reflowStage - 1];
					  tempdelta = reflowProfiles.profile5Temp[ovenParameters.reflowStage] - startTemp;
					  ovenParameters.tempSPDelta = (tempdelta / (float)reflowTimeDelta);

					  // get stage end temp
					  endTemp = reflowProfiles.profile5Temp[ovenParameters.reflowStage];

					  // set starting temp
					  startingTemp = round(ovenParameters.tempThermo);

					  break;
			  }

			  ovenParameters.setpointCal = 1;
		  }

		  // PID calculation
		  if (ovenParameters.PID_trig == 1)
		  {
			  // increase setpoint
			  if (startingTemp < endTemp && ovenParameters.reflowStage != 4) startingTemp = startingTemp + ovenParameters.tempSPDelta;

			  // cooling
			  if (startingTemp > endTemp && ovenParameters.reflowStage == 4) startingTemp = 0; // Turn OFF heater
			  //if (startingTemp > endTemp && ovenParameters.reflowStage == 4) startingTemp = round(startingTemp) + ovenParameters.tempSPDelta; // Hold constant drop with heater

			  TIM4->CCR2 =  PIDcalculation(&pid, &startingTemp); // set SSR1 Duty (Timer 4 channel 2)
			  ovenParameters.PID_trig = 0; // reset pid calculate flag
			  ovenParameters.addPoint = 1;
		  }

		  // Detect time to end current stage of reflow
		  if (timeSeconds == ovenParameters.endTimeStage && ovenParameters.reflowStage != 4)
		  {
			ovenParameters.setpointCal = 0; // trigger recalculation of parameters
			ovenParameters.reflowStage ++;	// move to next stage
		  }

		  break;
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

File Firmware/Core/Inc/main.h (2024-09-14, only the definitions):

#define AN_12V_Pin GPIO_PIN_13
#define AN_12V_GPIO_Port GPIOC
#define INHIBIT_Pin GPIO_PIN_14
#define INHIBIT_GPIO_Port GPIOC
#define BUZZER_Pin GPIO_PIN_15
#define BUZZER_GPIO_Port GPIOC
#define TOUCH_INT_Pin GPIO_PIN_0
#define TOUCH_INT_GPIO_Port GPIOA
#define TOUCH_INT_EXTI_IRQn EXTI0_IRQn
#define TOUCH_CS_Pin GPIO_PIN_1
#define TOUCH_CS_GPIO_Port GPIOA
#define DISPL_LED_Pin GPIO_PIN_2
#define DISPL_LED_GPIO_Port GPIOA
#define DISPL_DC_Pin GPIO_PIN_4
#define DISPL_DC_GPIO_Port GPIOA
#define DISPL_SCK_Pin GPIO_PIN_5
#define DISPL_SCK_GPIO_Port GPIOA
#define TOUCH_MISO_Pin GPIO_PIN_6
#define TOUCH_MISO_GPIO_Port GPIOA
#define DISPL_MOSI_Pin GPIO_PIN_7
#define DISPL_MOSI_GPIO_Port GPIOA
#define DISPL_RST_Pin GPIO_PIN_0
#define DISPL_RST_GPIO_Port GPIOB
#define DISPL_CS_Pin GPIO_PIN_1
#define DISPL_CS_GPIO_Port GPIOB
#define AN_3V3_Pin GPIO_PIN_2
#define AN_3V3_GPIO_Port GPIOB
#define FLASH_SCK_Pin GPIO_PIN_10
#define FLASH_SCK_GPIO_Port GPIOB
#define TERMO1_CS_Pin GPIO_PIN_12
#define TERMO1_CS_GPIO_Port GPIOB
#define TERMO2_CS_Pin GPIO_PIN_13
#define TERMO2_CS_GPIO_Port GPIOB
#define FLASH_MISO_Pin GPIO_PIN_14
#define FLASH_MISO_GPIO_Port GPIOB
#define FLASH_MOSI_Pin GPIO_PIN_15
#define FLASH_MOSI_GPIO_Port GPIOB
#define AN_T1_Pin GPIO_PIN_8
#define AN_T1_GPIO_Port GPIOA
#define FLASH_CS_Pin GPIO_PIN_15
#define FLASH_CS_GPIO_Port GPIOA
#define AUX_OUT2_Pin GPIO_PIN_4
#define AUX_OUT2_GPIO_Port GPIOB
#define AUX_OUT1_Pin GPIO_PIN_5
#define AUX_OUT1_GPIO_Port GPIOB
#define SSR2_Pin GPIO_PIN_6
#define SSR2_GPIO_Port GPIOB
#define SSR1_Pin GPIO_PIN_7
#define SSR1_GPIO_Port GPIOB
#define BUZZER_EN				// Enable buzzer
#define THERMAL_RUNAWAY_EN		// Enable thermal runaway protection
#define UART_EN					// Enable uart port (just data sending...)
#define KEEP_FLASH_DATA			// when firmware is reuploaded do you want to reset data in flash (profiles, settings...)
#define tickInSec				5
#define secInMin 				60
#define minInH 					60
#define FLASH_START_ADDR		2048000
#define STATE_INIT				0		// Starting state
#define STATE_ERROR				1		// If fault is detected - block the device
#define STATE_REFLOW			2		// Reflow mode
#define STATE_DRY				3		// Drying mode
#define RUNAWAY_TEMP			10		// thermal runaway temperature delta
#define RUNAWAY_TIME			20		// thermal runaway time delta
#define OVERTEMP_ERR			270		// Max alowed temperature
#define MIN_BUCK_VOLTAGE		3.1		// Minimum allowed buck output voltage
#define MIN_IN_VOLTAGE			10		// Minimum allowed input voltage
#define R1_3V3					6800	// R1 of voltage divider for 12V
#define R2_3V3					1000	// R2 of voltage divider for 12V
#define R1_12V					100		// R1 on 3.3V measuring
#define R1_NTC					10000	// NTC resistance
#define R2_NTC					10000	// NTC R2 resistance
#define NTC_MAX_TEMP			80		// Max allowed temperature in elektronics compartment

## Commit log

2024-05-21 first commit, PCB done(not tested yet), firmware started(LCD works, touch screen works)
    [PCB.kicad_pcb, PCB.kicad_sch, Spacer_PCB-Screen v3.stl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]
2024-06-22 PCB done and ordered, touch screen and TFT works, flash works, EdternalLoader, GUI partialy done
    [LoggedData.csv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]
2024-07-27 PCB works (Problems: safety switch, analog inputs mistake), ExternalLoader works, gui in progress
    [Front_frame v8.stl, PCB.kicad_pcb, PCB.kicad_sch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]
2024-07-27 SW: 5Hz reading loop, averaging temperature, gui live temperature, time counter
    [dg-301-5_0-2P.step, glass.stp]
2024-07-30 timer corrected, PID base
2024-08-05 PCB update, firmaware
    usb problem -> repaired
    firmware update: pid, PWM, gui
    [LoggedData.csv, PCB.kicad_pcb, PCB.kicad_sch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]
2024-08-05 Firmware update
    simplified PID, PID tuned, gui rapair and added features
2024-08-07 SW Update
    working reflow, following the temperature profile, changed and added features to plots, active reflow stage indicator
2024-08-07 SW Update
    Over temperature protection
2024-08-11 SW update
    thermal runaway, better reflow reference following, detect first boot and init presset values
    [Front_frame v8.stl, Front_frame v9.stl]
2024-08-11 SW update
    saving variables to flash and allowing user to reset them from program when uploading, repaired bugs in reflow profile settings
    [main.c, main.h]
2024-08-12 Documentation update
    [LoggedData.csv]
2024-09-14 bugfix
    Reflow profile - temperature can now be set to 0, time of cooling is not limited to 300
    [main.h]
2024-09-14 bugfix, updates
    bugfix: reflow timing, plot generating
    updates: start/stop buttons are now one button
    [main.c]
2024-09-14 bugfix
    keep start/stop button state when returning to main screen
2024-09-15 Bugfix
    plot repair and variable init after finished reflow
    [main.c]
2025-07-20 Bugfix
    changed reset values of plot x-axis numbers
    [PCB-F_Mask.dxf, Stencil v2.stl]
2025-07-25 update
    added STEP files and external electronics case
    [Back_frame_external v19.step, Back_frame_external v19.stl, Base_external v7.step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]

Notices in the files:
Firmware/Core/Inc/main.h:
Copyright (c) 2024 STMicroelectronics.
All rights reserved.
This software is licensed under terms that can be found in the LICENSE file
